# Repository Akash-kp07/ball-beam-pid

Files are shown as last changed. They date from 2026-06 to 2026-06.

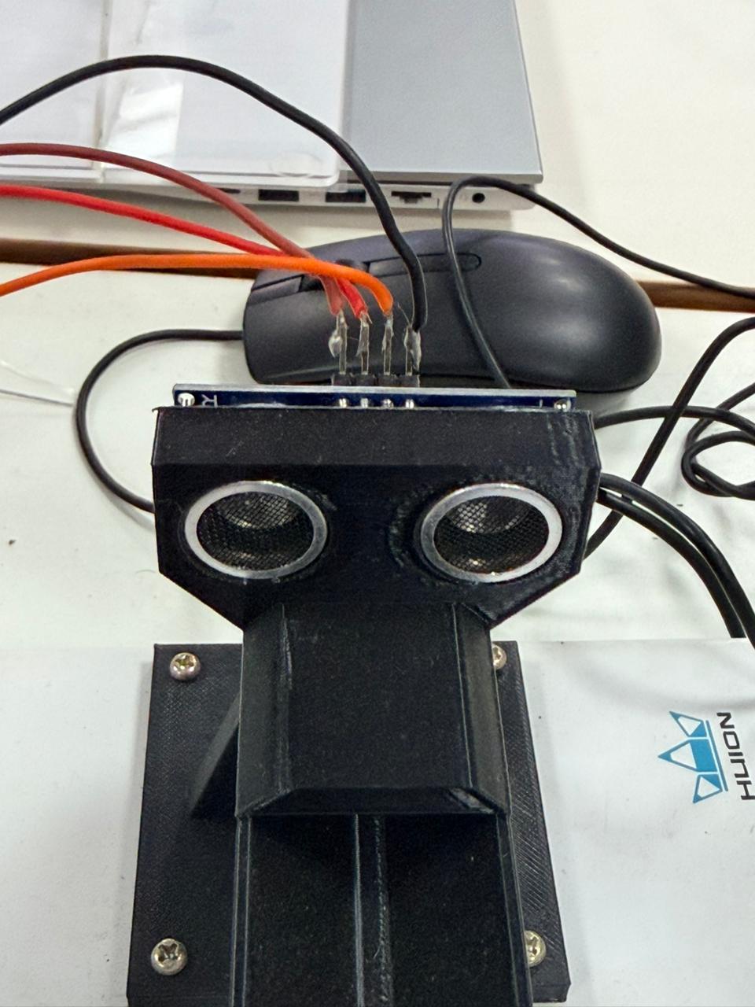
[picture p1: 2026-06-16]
Media/Photos/ball_beam_pid_img2.jpeg

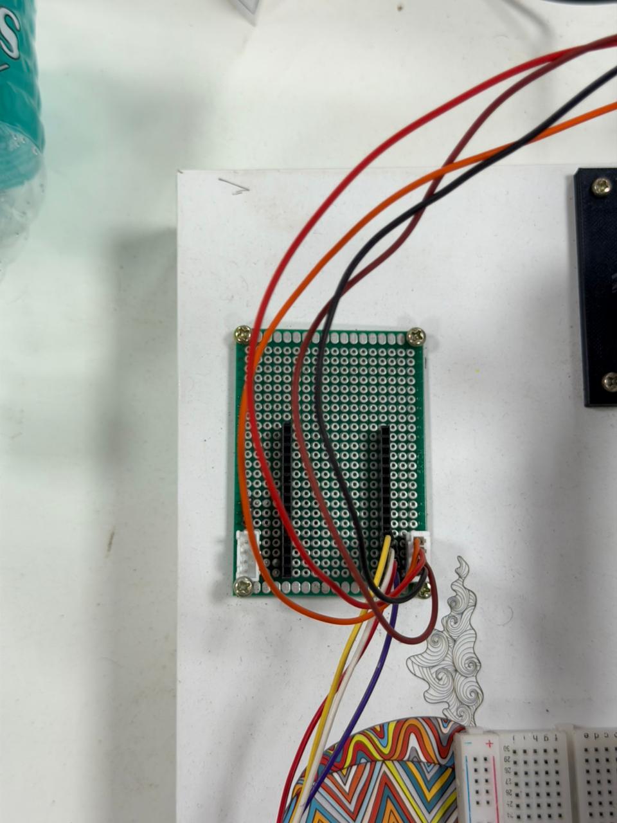
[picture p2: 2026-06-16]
Media/Photos/ball_beam_pid_img1.jpeg

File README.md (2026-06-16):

# Ball and Beam PID Control System

A closed-loop ball balancing system using an ultrasonic sensor, servo motor, and a PID controller with Kalman filtering — built on Arduino.

## Demo

https://github.com/user-attachments/assets/a7be61a5-dee0-4388-ae0d-bb8cbe6352cf

---

## How It Works

An ultrasonic sensor measures the ball's position on the beam. A PID controller computes the correction needed and drives a servo motor to tilt the beam, keeping the ball at a target position.

```
[Ultrasonic Sensor] → [Kalman Filter] → [PID Controller] → [Servo Motor] → [Beam]
         ↑_______________________________________________________|
```

---

## Hardware

| Component | Details |
|---|---|
| Microcontroller | Arduino (Uno/Nano) |
| Sensor | HC-SR04 Ultrasonic |
| Actuator | Servo Motor |
| Beam range | 2.5 cm – 25 cm |

### Pin Connections

| Pin | Function |
|-----|---|
| D8  | Servo signal |
| D9  | Ultrasonic TRIG |
| D10 | Ultrasonic ECHO |

---

## Software Features

- **PID Control** — Proportional, Integral, Derivative with dynamic gain scaling based on target distance
- **Kalman Filter** — Smooths noisy ultrasonic readings
- **Deadband** — Eliminates servo jitter near setpoint (7% of target)
- **Derivative filter** — Low-pass filter on derivative term (α = 0.3) to reduce noise amplification
- **Slew limiter** — Limits servo angular velocity based on error magnitude (prevents overshoot)
- **Integral windup clamp** — Integral term clamped to ±20
- **Serial setpoint control** — Target position adjustable live via Serial (5–22 cm range)

---

## PID Gains

| Gain | Base Value |
|---|---|
| Kp | 1.9 |
| Ki | 0.3 |
| Kd | 1.2 |

Gains are scaled dynamically: `K_scaled = K_base × (target / 15.0)`

---

## Serial Interface

Send a float value (5.0 – 22.0) over Serial at **9600 baud** to update the target position:

```
15.0   → sets target to 15 cm
10.0   → sets target to 10 cm
```

Serial output format (for real-time plotting):
```
pos:14.87,target:15.00,servo:46
```
---

## Web GUI

Flask-based browser interface for live control.
- Slider to set target distance (5–22 cm)
- Live position readback every 200ms
- Runs on http://localhost:5000

Setup:
```
  cd Code/controller
  bash setup.sh
  source venv/bin/activate
  python app.py

```
---

## Code Structure

```
Code/
├── ball_beam_pid/
|   └── ball_beam_pid.ino
└── controller/
    ├── app.py
    └── setup.sh
Media/
├── Photos/             # System photos
└── Videos/             # Demo videos
```

---

## Getting Started

1. Wire hardware per pin table above
2. Open `Code/ball_beam_pid.ino` in Arduino IDE
3. Upload to Arduino
4. Open Serial Monitor at **9600 baud**
5. Send target distance (e.g. `15.0`) to begin

---

## Team
- [Akash KP](https://github.com/Akash-kp07)
- [Abhik Allingil](https://github.com/abhikallingil)

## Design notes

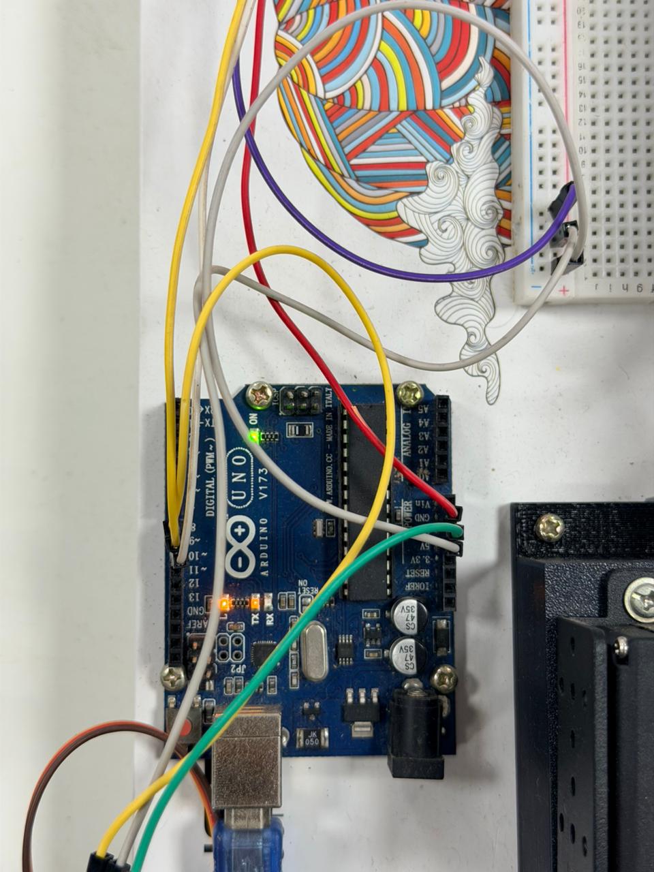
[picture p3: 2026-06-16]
Media/Photos/ball_beam_pid_img4.jpeg

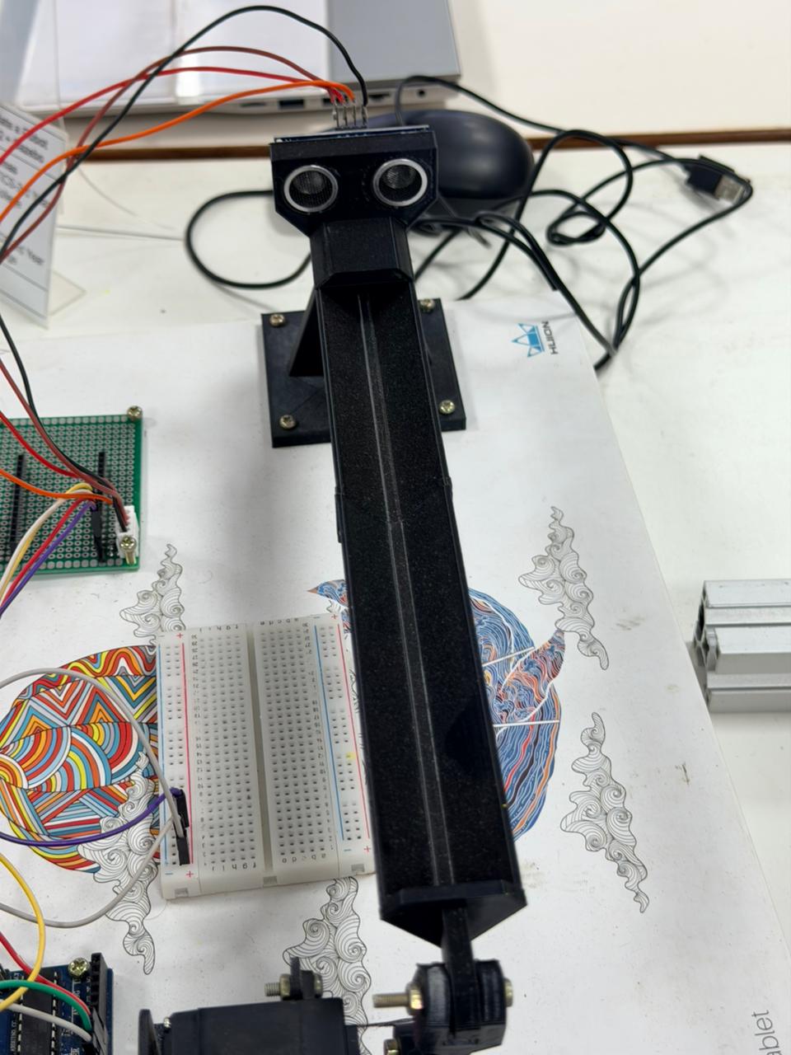
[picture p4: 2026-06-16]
Media/Photos/ball_beam_pid_img3.jpeg

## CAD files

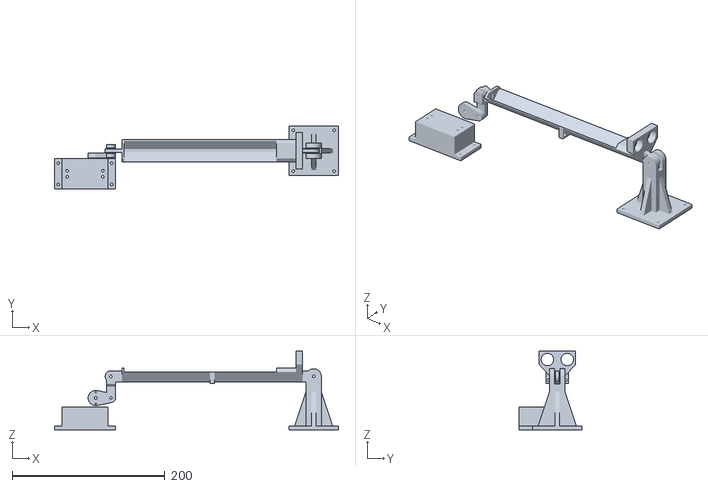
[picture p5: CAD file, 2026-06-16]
CAD/Assembly.stl
372.2 x 82.7 x 103.0

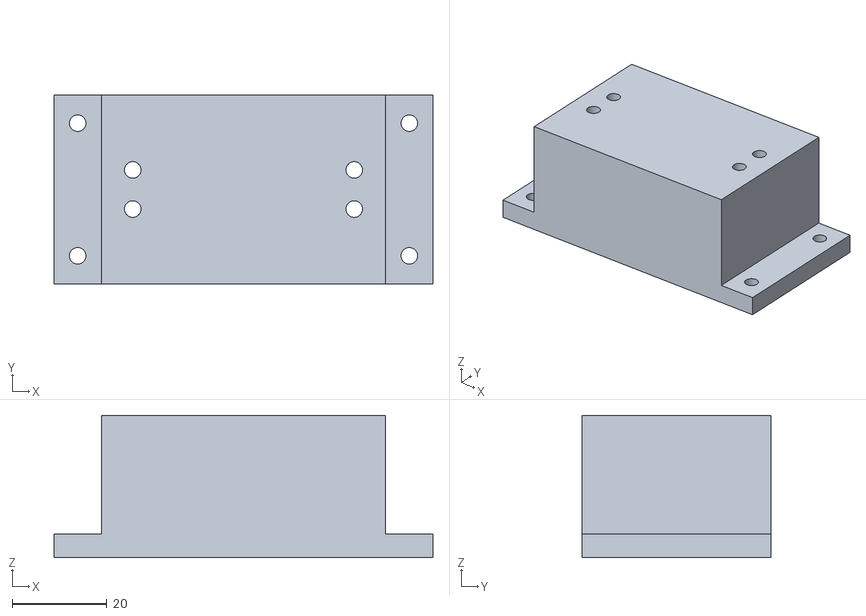
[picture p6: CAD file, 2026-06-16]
CAD/servo pocket.stl
80.0 x 40.0 x 30.0

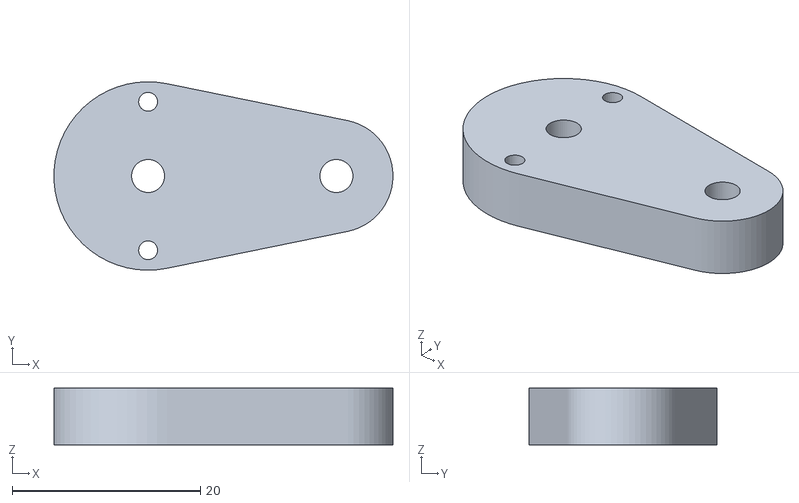
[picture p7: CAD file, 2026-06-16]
CAD/lower linkage.stl
36.0 x 20.0 x 6.00

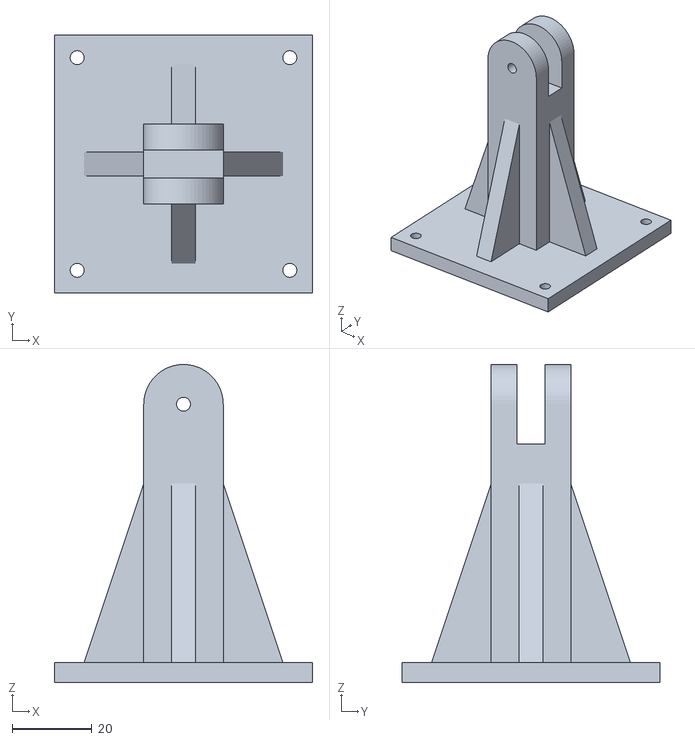
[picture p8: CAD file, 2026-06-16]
CAD/fulkrum1.stl
65.0 x 65.0 x 80.0

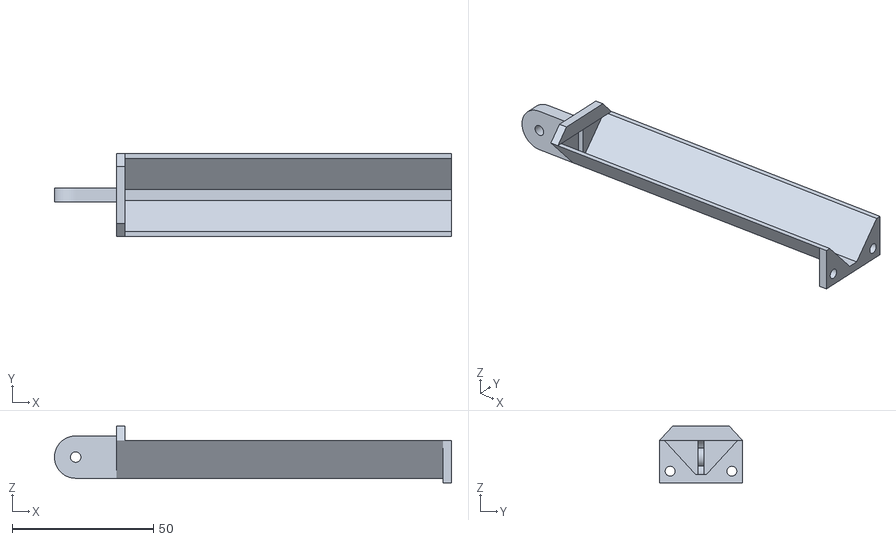
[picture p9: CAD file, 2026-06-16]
CAD/beam2 (1).stl
140.5 x 29.5 x 20.2

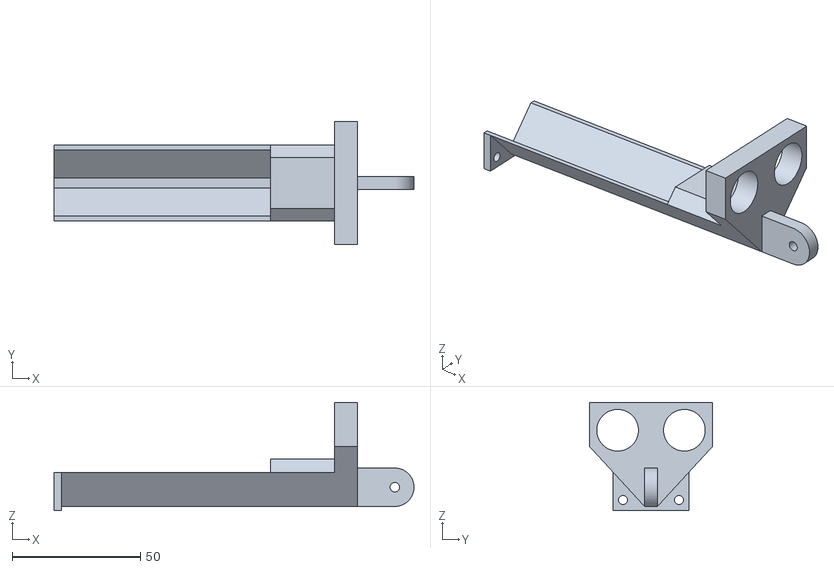
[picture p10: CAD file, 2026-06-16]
CAD/beam1.stl
140.5 x 48.0 x 42.3

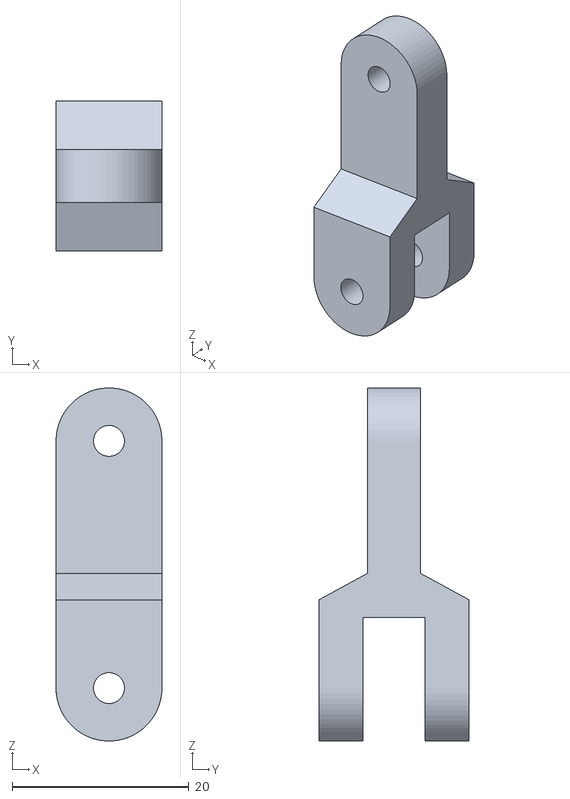
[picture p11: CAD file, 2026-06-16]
CAD/upper linkage1.stl
12.0 x 17.0 x 40.0

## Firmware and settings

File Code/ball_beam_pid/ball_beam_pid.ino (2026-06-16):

#include <Servo.h>

// ── Pins ─────────────────────────────────────────────
const int SERVO_PIN = 8;
const int TRIG_PIN  = 9;
const int ECHO_PIN  = 10;

// ── Beam geometry ────────────────────────────────────
float TARGET_DIST = 15.0;   // default
const float DIST_MIN = 2.5;
const float DIST_MAX = 25.0;

// ── Servo limits ─────────────────────────────────────
const int SERVO_CENTER  = 44;
const int SERVO_MIN_DEG = 20;
const int SERVO_MAX_DEG = 100;

// ── Kalman Filter ────────────────────────────────────
struct KalmanFilter {
  float q, r, p, x, k;

  KalmanFilter(float meas_err, float est_err, float proc_var)
    : q(proc_var), r(meas_err), p(est_err), x(0), k(0) {}

  float update(float z) {
    p = p + q;
    k = p / (p + r);
    x = x + k * (z - x);
    p = (1 - k) * p;
    return x;
  }
};

KalmanFilter kf(0.4, 0.4, 0.05);

// ── PID gains ────────────────────────────────────────
float KP_BASE = 1.9;
float KI_BASE = 0.3;
float KD_BASE = 1.2;

// ── PID variables ────────────────────────────────────
float pid_integral = 0.0;
float pid_prev_err = 0.0;
float filtered_deriv = 0.0;

// ── Globals ──────────────────────────────────────────
Servo servo;
float ball_position = 0;

int prev_servo_angle = SERVO_CENTER;
unsigned long prev_time = 0;

// ── Ultrasonic sensor ────────────────────────────────
float readRawDistance() {
  digitalWrite(TRIG_PIN, LOW);
  delayMicroseconds(2);
  digitalWrite(TRIG_PIN, HIGH);
  delayMicroseconds(10);
  digitalWrite(TRIG_PIN, LOW);

  long dur = pulseIn(ECHO_PIN, HIGH, 30000);
  if (dur == 0) return -1;

  return dur * 0.0343 / 2.0;
}

bool readSensor() {
  float raw = readRawDistance();
  if (raw < DIST_MIN || raw > DIST_MAX) return false;

  ball_position = kf.update(raw);
  return true;
}

// ── PID controller ───────────────────────────────────
float computePID(float dt) {
  float error = ball_position - TARGET_DIST;

  float deadband = 0.07 * TARGET_DIST;
  if (abs(error) < deadband) {
    pid_integral = 0;
    pid_prev_err = error;
    filtered_deriv = 0;
    return 0;
  }

  float scale = TARGET_DIST / 15.0;

  float KP = KP_BASE * scale;
  float KI = KI_BASE * scale;
  float KD = KD_BASE * scale;

  pid_integral += error * dt;
  pid_integral = constrain(pid_integral, -20, 20);

  float derivative = (error - pid_prev_err) / dt;
  filtered_deriv = 0.7 * filtered_deriv + 0.3 * derivative;

  pid_prev_err = error;

  return (KP * error) + (KI * pid_integral) + (KD * filtered_deriv);
}

// ── Slew limiter ─────────────────────────────────────
int slewServo(int target_angle, float error) {
  float abs_err = abs(error);

  int max_step;
  if (abs_err > 5)      max_step = 15;
  else if (abs_err > 3) max_step = 8;
  else if (abs_err > 2) max_step = 5;
  else                  max_step = 3;

  int delta = target_angle - prev_servo_angle;
  delta = constrain(delta, -max_step, max_step);

  return prev_servo_angle + delta;
}

// ── Serial input (UI compatible) ─────────────────────
void checkSerial() {
  if (Serial.available()) {
    float newTarget = Serial.parseFloat();

    if (newTarget >= 5 && newTarget <= 22) {   // ✅ your range
      TARGET_DIST = newTarget;
      Serial.print("New Target: ");
      Serial.println(TARGET_DIST);
    }
  }
}

// ── Setup ────────────────────────────────────────────
void setup() {
  Serial.begin(9600);   // ✅ MUST match Python

  pinMode(TRIG_PIN, OUTPUT);
  pinMode(ECHO_PIN, INPUT);

  servo.attach(SERVO_PIN);
  servo.write(SERVO_CENTER);

  delay(500);

  kf.x = TARGET_DIST;

  Serial.println("System Ready");
  prev_time = micros();
}

// ── Loop ─────────────────────────────────────────────
void loop() {
  checkSerial();

  unsigned long now = micros();
  float dt = (now - prev_time) / 1e6;
  prev_time = now;

  if (dt <= 0 || dt > 0.5) return;

  if (!readSensor()) {
    servo.write(SERVO_CENTER);
    prev_servo_angle = SERVO_CENTER;
    pid_integral = 0;
    pid_prev_err = 0;
    filtered_deriv = 0;
    return;
  }

  float pid_out = computePID(dt);

  int raw_angle = SERVO_CENTER + (int)pid_out;
  raw_angle = constrain(raw_angle, SERVO_MIN_DEG, SERVO_MAX_DEG);

  int servo_angle = slewServo(raw_angle, ball_position - TARGET_DIST);
  servo_angle = constrain(servo_angle, SERVO_MIN_DEG, SERVO_MAX_DEG);

  servo.write(servo_angle);
  prev_servo_angle = servo_angle;

  // Optional debug
  Serial.print("pos:");
  Serial.print(ball_position);
  Serial.print(",target:");
  Serial.print(TARGET_DIST);
  Serial.print(",servo:");
  Serial.println(servo_angle);

  delay(20);
}

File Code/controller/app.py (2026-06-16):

from flask import Flask, render_template_string, request
import serial
import time
import threading

# 🔧 CHANGE THIS PORT
SERIAL_PORT = 'COM7'   # Windows → COM3, Linux → /dev/ttyUSB0

ser = serial.Serial(SERIAL_PORT, 9600, timeout=1)
time.sleep(2)

app = Flask(__name__)

# ── Global variable ──────────────────────────────────
current_position = 0

# ── Serial Reader Thread ─────────────────────────────
def read_serial():
    global current_position

    while True:
        try:
            line = ser.readline().decode().strip()

            if "pos:" in line:
                parts = line.split(",")

                for p in parts:
                    if "pos:" in p:
                        value = float(p.replace("pos:", ""))
                        current_position = round(value)   # ✅ rounding

        except:
            pass

# ── HTML UI ──────────────────────────────────────────
HTML = """
<!DOCTYPE html>
<html>
<head>
    <title>Distance Control</title>
    <style>
        body {
            background: #0f172a;
            color: #e2e8f0;
            text-align: center;
            font-family: Arial;
        }

        h1 {
            margin-top: 50px;
        }

        .slider {
            width: 300px;
        }

        .box {
            margin-top: 40px;
        }
    </style>
</head>
<body>

<h1>Target Distance Controller</h1>

<div class="box">
    <h2>Target: <span id="target">15</span> cm</h2>
    <h2>Current: <span id="current">0</span> cm</h2>

    <input type="range" min="5" max="22" value="15" class="slider" id="slider">
</div>

<script>
let slider = document.getElementById("slider");
let target = document.getElementById("target");
let current = document.getElementById("current");

// Send target value
slider.oninput = function() {
    target.innerHTML = this.value;
    fetch("/set?value=" + this.value);
}

// Get current position every 200ms
setInterval(() => {
    fetch("/position")
    .then(res => res.text())
    .then(data => {
        current.innerHTML = data;
    });
}, 200);

</script>

</body>
</html>
"""

# ── Routes ───────────────────────────────────────────
@app.route('/')
def index():
    return render_template_string(HTML)

@app.route('/set')
def set_value():
    value = request.args.get('value')

    if value:
        ser.write((value + '\\n').encode())
        print("Sent:", value)

    return "OK"

@app.route('/position')
def get_position():
    return str(current_position)

# ── Start everything ─────────────────────────────────
if __name__ == '__main__':
    threading.Thread(target=read_serial, daemon=True).start()
    app.run(host='0.0.0.0', port=5000)

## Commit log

2026-06-16 Initial commit: Ball and beam PID control system
2026-06-16 Update Arduino sketch file references in README
2026-06-16 Add CAD design files
    [Assembly.stl, beam1.stl, beam2 (1).stl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]
